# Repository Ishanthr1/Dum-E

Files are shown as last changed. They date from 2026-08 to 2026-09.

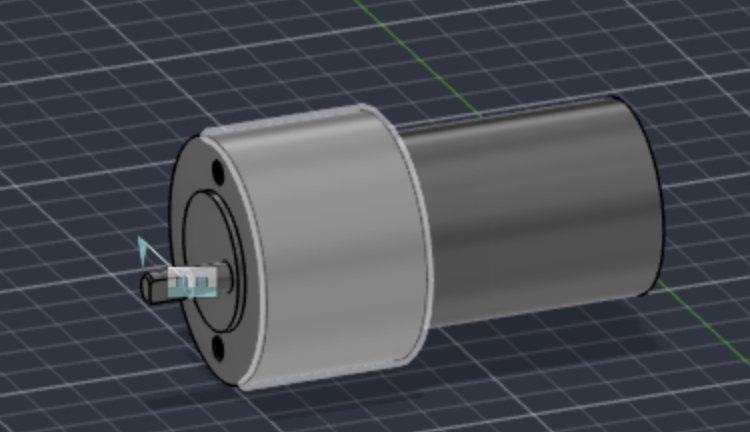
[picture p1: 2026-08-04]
images/Screenshot 2026-08-04 at 3.25.16 PM.png

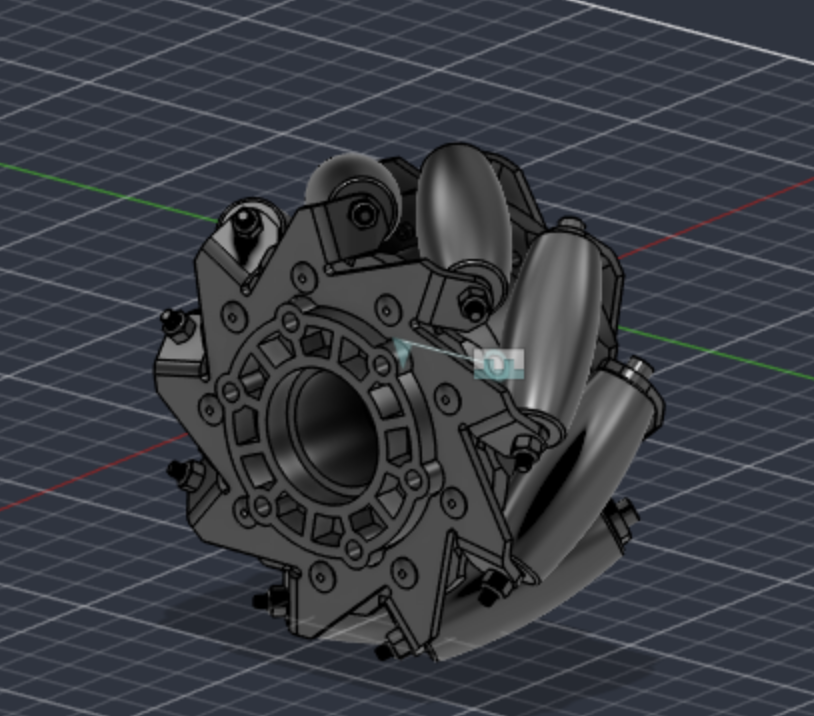
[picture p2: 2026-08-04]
images/Screenshot 2026-08-04 at 3.25.08 PM.png

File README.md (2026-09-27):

# Dum-E

A voice controlled autonomous mobile manipulator built from scratch. Dum-E is a 6 DOF robotic arm mounted on a holonomic (mecanum) drive base named after Tony Stark's clumsy robot assistant.

Screenshot 2026-08-04 at 3 30 15 PM

## Overview and How it Works

DumE is a robotic platform with two main sub assemblies: a holonomic drive base and a 6 DOF arm. Both the chassis and the arm are designed and built from scratch from individually sourced aluminum, hardware, and 3D printed parts.

- **Holonomic drive:** four mecanum wheels for omnidirectional movement (forward, strafe, and rotate in place).
- **6-DOF arm:** six high torque servos with a custom parallel jaw gripper.
- **Stereo vision head:** dual Raspberry Pi cameras at a fixed baseline.
- **Far-field audio:** ReSpeaker mic array plus an amplified speaker.

CAD files for the chassis, arm, and 3D printed parts are in the [`cad/`](cad/) folder.

## Why?

I have always been interested in Robotics and building this project can help me improve me skills. There are already many prebuilt things I can buy to help speed up this project but I want to make something actually worthwhile which is why I am building everything from scratch from individually sourced parts. I also wanted to make something cool!

## Bill of Materials

Full parts list (also available as [`BOM.csv`](BOM.csv)). A Raspberry Pi 5 is required but is owned separately and not included in the total below.

| Item | Qty | Unit (USD) | Total | Where to buy |
|---|-----|---|---|---|
| Hiwonder xArm1S 6DOF arm (unassembled) | 1 | 199.99 | 199.99 | [Amazon](https://www.amazon.com/Programming-Powerful-Intelligent-Featuring-Unassembled/dp/B08FT31C5N) |
| MC200 mecanum chassis + 4 encoder motors | 1 | 73.99 | 73.99 | [Amazon](https://www.amazon.com/dp/B09KL37P43) |
| Raspberry Pi Camera Module 3 | 2 | 36.00 | 72.00 | [Amazon](https://www.amazon.com/Arducam-Raspberry-Camera-Autofocus-15-22pin/dp/B0C9PYCV9S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) |
| microSD card | 1 | 33.06 | 33.06 | [Amazon](https://www.amazon.com/SanDisk-Extreme-microSDXC-Memory-Adapter/dp/B09X7C7LL1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) |
| LiPo battery 3S 11.1V (XT60) | 1 | 32.99 | 32.99 | [Amazon](https://www.amazon.com/OVONIC-Connector-Airplane-Helicopter-Quadcopter/dp/B0D8SFBHV6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) |
| Helping Hands | 1 | 25.99 | 25.99 | [Amazon](https://www.amazon.com/Helping-Soldering-Workshop-Non-slip-Weighted/dp/B07MDKXNPC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) |
| L298N dual H-bridge motor driver | 2 | 9.99 | 19.98 | [Amazon](https://www.amazon.com/BOJACK-H-Bridge-Controller-Intelligent-Mega2560/dp/B0C5JCF5RS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) |
| ESP32 dev board — motor controller | 1 | 18.99 | 18.99 | [Amazon](https://www.amazon.com/YEJMKJ-Development-ESP-WROOM-32-Microcontroller-Integrated/dp/B0CNGPQX2V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) |
| Buck converter 7.5V 6A — arm rail | 1 | 17.49 | 17.49 | [Amazon](https://www.amazon.com/s?k=DC-DC+buck+converter+7.5V+6A+adjustable) |
| LiPo balance charger (3S) | 1 | 16.99 | 16.99 | [Amazon](https://www.amazon.com/SSUPCHG-Battery-Charger-Balance-Chargers/dp/B0FPDJ5Q57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) |
| ReSpeaker 2-Mics Pi HAT | 1 | 13.99 | 13.99 | [Seeed Studio](https://www.seeedstudio.com/ReSpeaker-2-Mics-Pi-HAT.html) |
| Buck converter 5V 5A (UBEC) | 1 | 11.99 | 11.99 | [Amazon](https://www.amazon.com/EC-Buying-Mini560-Adjustable-Electronics/dp/B0GW8JMN9J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) |
| LiPo charging safety bag | 1 | 11.99 | 11.99 | [Amazon](https://www.amazon.com/HOOVO-Battery-Fireproof-Explosionproof-Protector/dp/B0B4SGTRDC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) |
| Pi 5 camera adapter cable | 1 | 9.99 | 9.99 | [Amazon](https://www.amazon.com/Wonrabai-2PCS-Official-Flexible-Compatible-Raspberry/dp/B0GJ5CJWDF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) |
| XT60 connectors + power wiring | 1 | 8.99 | 8.99 | [Amazon](https://www.amazon.com/Pairs-Female-Connector-Silicon-Battery/dp/B07QH249CR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) |
| Inline fuse holder + master switch | 1 | 8.99 | 8.99 | [Amazon](https://www.amazon.com/Gebildet-12V-220V-Button-Switch-Driving/dp/B0FJXTXZ43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) |
| Dupont jumper wire kit (M-M, M-F, F-F) | 1 | 8.99 | 8.99 | [Amazon](https://www.amazon.com/Solderless-Multicolor-Electronic-Breadboard-Protoboard/dp/B09FNXKXDW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) |
| Zip ties | 1 | 8.97 | 8.97 | [Amazon](https://www.amazon.com/Zip-Tie-Mounts-SeuYeugX-Management/dp/B08XLR46Y7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) |
| MAX98357A I2S amplifier | 1 | 6.88 | 6.88 | [Amazon](https://www.amazon.com/MAX98357-MAX98357A-Amplifier-Interface-Raspberry/dp/B0DPJRLMDJ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) |
| Micro-USB data cable (ESP32) | 1 | 6.59 | 6.59 | [Amazon](https://www.amazon.com/DIYmall-Micro-USB-Charging-Transfer-Android-Phone/dp/B0C89Q81FW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) |
| Speaker 3in 8Ω 1W | 1 | 5.58 | 5.58 | [Amazon](https://www.amazon.com/Micro-Internal-speaker-Small-Speakers/dp/B0H3PPB2HN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) |
| Velcro strips | 1 | 4.89 | 4.89 | [Amazon](https://www.amazon.com/Art3d-Sticky-Double-Sided-Command-Adhesive/dp/B0B58FGF8H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) |
| **Total** | | | **619.31** | |

## Build Journal

Day by day progress is logged in Journal.md.

## License

MIT see [`LICENSE`](LICENSE).

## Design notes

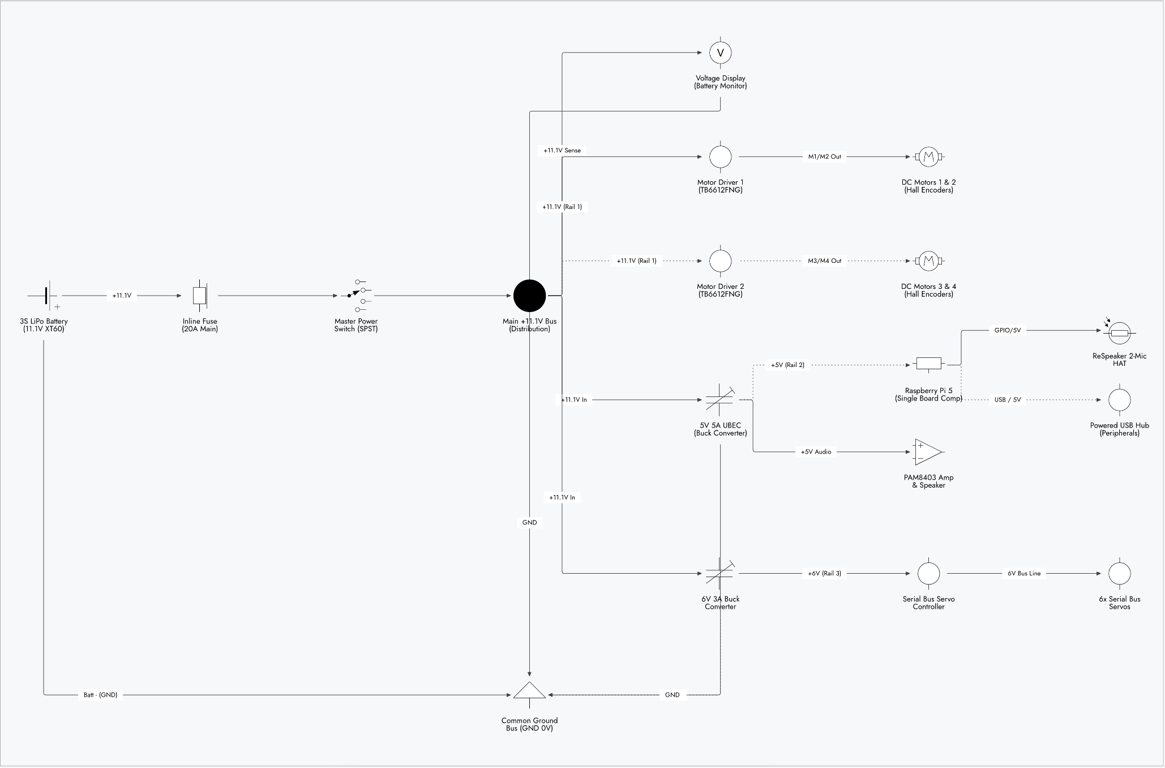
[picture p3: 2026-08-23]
DumE Schematics.png

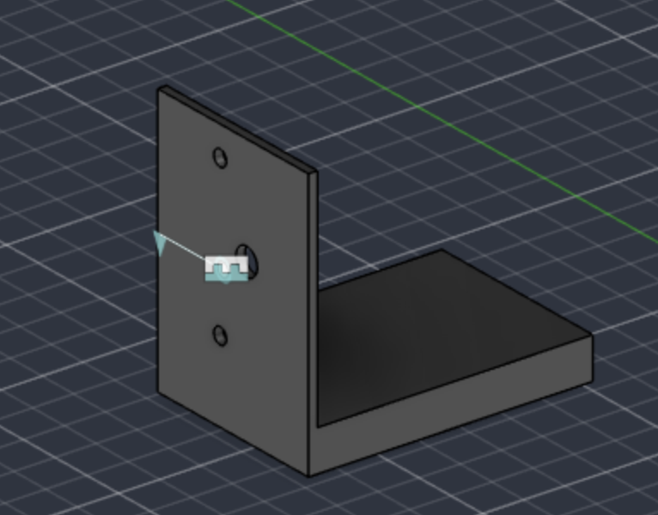
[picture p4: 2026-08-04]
images/Screenshot 2026-08-04 at 3.24.59 PM.png

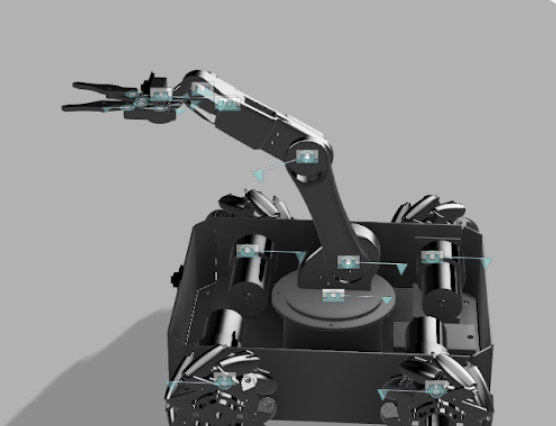
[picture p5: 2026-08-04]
images/Screenshot 2026-08-04 at 3.24.10 PM.png

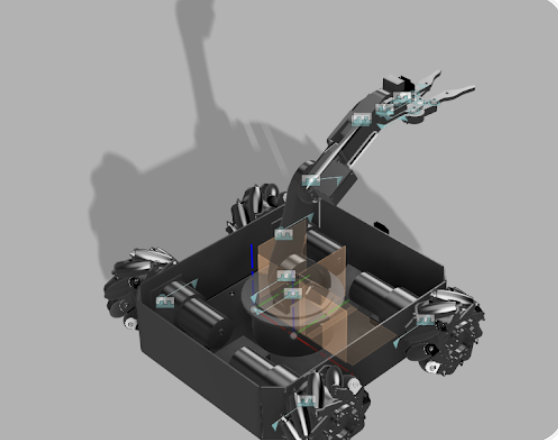
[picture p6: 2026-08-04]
images/Screenshot 2026-08-04 at 3.24.02 PM.png

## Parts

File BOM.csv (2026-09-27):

Item | Qty | Unit (USD) | Total (USD) | Where to buy | URL
Hiwonder xArm1S 6DOF arm (unassembled) | 1 | 199.99 | 199.99 | Amazon | https://www.amazon.com/Programming-Powerful-Intelligent-Featuring-Unassembled/dp/B08FT31C5N
MC200 mecanum chassis + 4 encoder motors | 1 | 73.99 | 73.99 | Amazon | https://www.amazon.com/dp/B09KL37P43
Raspberry Pi Camera Module 3 | 2 | 36.00 | 72.00 | Amazon | https://www.amazon.com/Arducam-Raspberry-Camera-Autofocus-15-22pin/dp/B0C9PYCV9S
Buck converter 7.5V 6A - arm rail | 1 | 17.49 | 17.49 | Amazon | https://www.amazon.com/s?k=DC-DC+buck+converter+7.5V+6A+adjustable
ReSpeaker 2-Mics Pi HAT | 1 | 13.99 | 13.99 | Seed Studio | https://www.seeedstudio.com/ReSpeaker-2-Mics-Pi-HAT.html
LiPo balance charger (3S) | 1 | 16.99 | 16.99 | Amazon | https://www.amazon.com/SSUPCHG-Battery-Charger-Balance-Chargers/dp/B0FPDJ5Q57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
Buck converter 5V 5A (UBEC) | 1 | 11.99 | 11.99 | Amazon | https://www.amazon.com/EC-Buying-Mini560-Adjustable-Electronics/dp/B0GW8JMN9J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
XT60 connectors + power wiring | 1 | 8.99 | 8.99 | Amazon | https://www.amazon.com/Pairs-Female-Connector-Silicon-Battery/dp/B07QH249CR?sp_csd=d2lkZ2V0TmFtZT1zcF9hdGY
Inline fuse holder + master switch | 1 | 8.99 | 8.99 | Amazon | https://www.amazon.com/Gebildet-12V-220V-Button-Switch-Driving/dp/B0FJXTXZ43
LiPo battery 3S 11.1V (XT60) | 1 | 32.99 | 32.99 | Amazon | https://www.amazon.com/OVONIC-Connector-Airplane-Helicopter-Quadcopter/dp/B0D8SFBHV6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
ESP32 dev board - motor controller | 1 | 18.99 | 18.99 | Amazon | https://www.amazon.com/YEJMKJ-Development-ESP-WROOM-32-Microcontroller-Integrated/dp/B0CNGPQX2V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
L298N dual H-bridge motor driver | 2 | 9.99 | 19.98 | Amazon | https://www.amazon.com/BOJACK-H-Bridge-Controller-Intelligent-Mega2560/dp/B0C5JCF5RS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
microSD card | 1 | 33.06 | 33.06 | Amazon | https://www.amazon.com/SanDisk-Extreme-microSDXC-Memory-Adapter/dp/B09X7C7LL1
Pi 5 camera adapter cable | 1 | 9.99 | 9.99 | Amazon | https://www.amazon.com/Wonrabai-2PCS-Official-Flexible-Compatible-Raspberry/dp/B0GJ5CJWDF?nsdOptOutParam=true
MAX98357A I2S amplifier | 1 | 6.88 | 6.88 | Amazon | https://www.amazon.com/MAX98357-MAX98357A-Amplifier-Interface-Raspberry/dp/B0DPJRLMDJ
Speaker 3in 8Ω 1W | 1 | 5.58 | 5.58 | Amazon | https://www.amazon.com/Micro-Internal-speaker-Small-Speakers/dp/B0H3PPB2HN
Micro-USB data cable (ESP32) | 1 | 6.59 | 6.59 | Amazon | https://www.amazon.com/DIYmall-Micro-USB-Charging-Transfer-Android-Phone/dp/B0C89Q81FW
LiPo charging safety bag | 1 | 11.99 | 11.99 | Amazon | https://www.amazon.com/HOOVO-Battery-Fireproof-Explosionproof-Protector/dp/B0B4SGTRDC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
Dupont jumper wire kit (M-M, M-F, F-F) | 1 | 8.99 | 8.99 | Amazon | https://www.amazon.com/Solderless-Multicolor-Electronic-Breadboard-Protoboard/dp/B09FNXKXDW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
Zip Ties | 1 | 8.97 | 8.97 | Amazon | https://www.amazon.com/Zip-Tie-Mounts-SeuYeugX-Management/dp/B08XLR46Y7?sp_csd=d2lkZ2V0TmFtZT1zcF9hdGY
Velcro Strips | 1 | 4.89 | 4.89 | Amazon | https://www.amazon.com/Art3d-Sticky-Double-Sided-Command-Adhesive/dp/B0B58FGF8H
Helping Hands | 1 | 25.99 | 25.99 | Amazon | https://www.amazon.com/Helping-Soldering-Workshop-Non-slip-Weighted/dp/B07MDKXNPC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

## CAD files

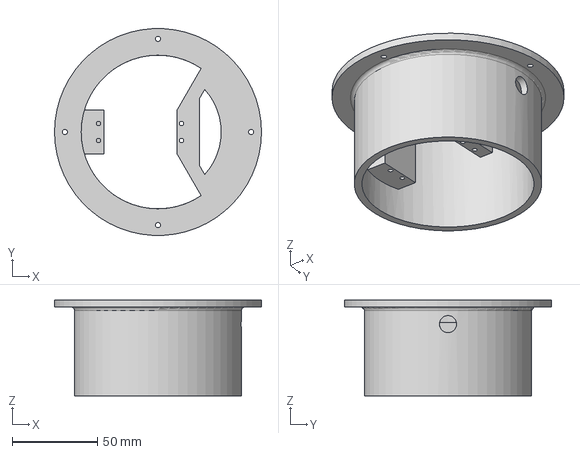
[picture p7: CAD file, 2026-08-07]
cad/base.stp
121.2 x 121.1 x 56.0 mm

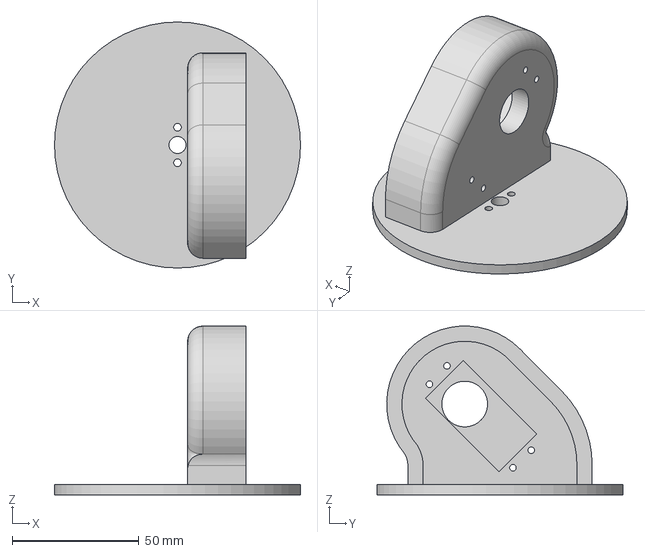
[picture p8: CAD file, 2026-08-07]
cad/Chassis+for+Robot.stp
97.0 x 97.0 x 66.5 mm

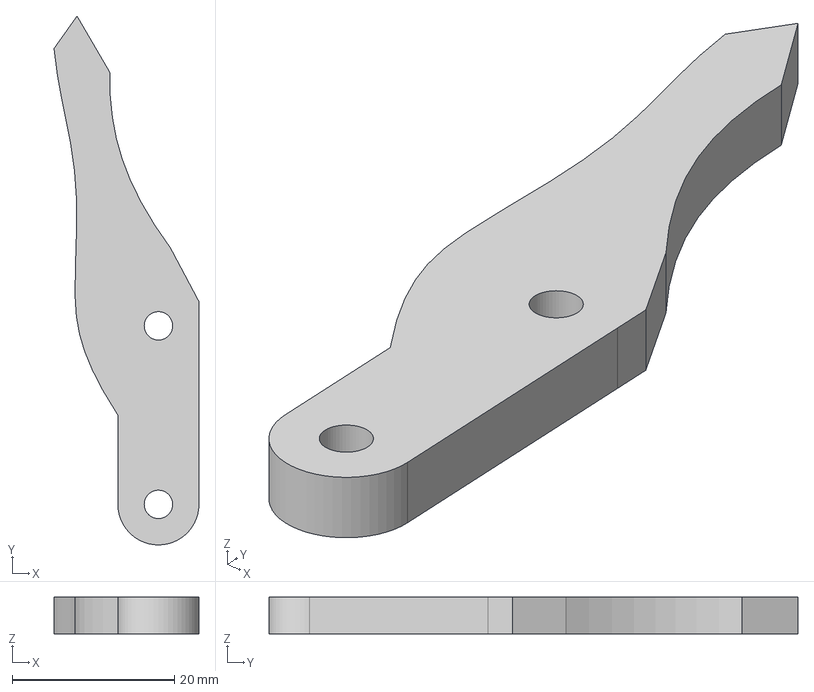
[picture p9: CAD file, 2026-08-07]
cad/Claw.stp
17.9 x 65.2 x 4.50 mm

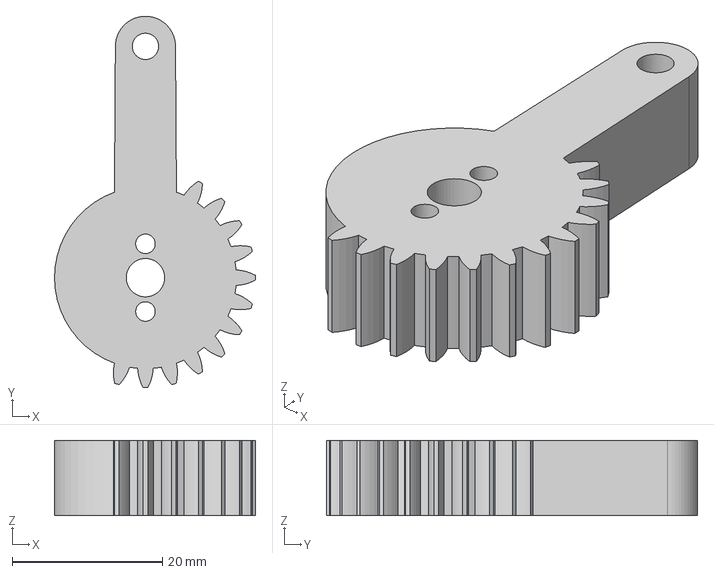
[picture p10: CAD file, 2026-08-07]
cad/Gear+for+Claw.stp
26.7 x 49.4 x 10.0 mm

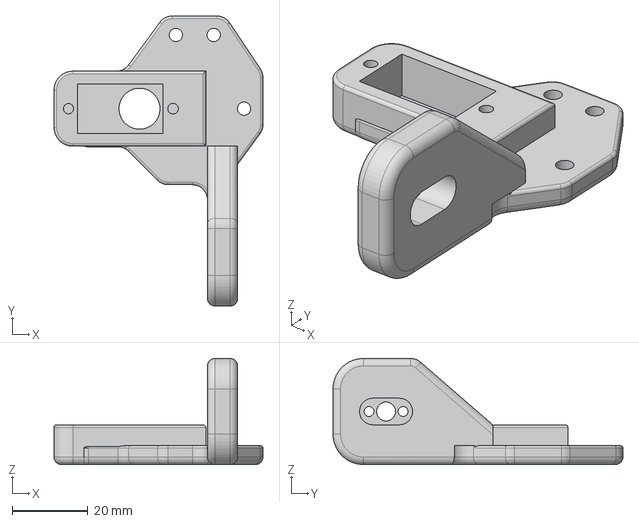
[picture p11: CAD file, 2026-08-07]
cad/Claw+Link.stp
55.2 x 76.5 x 28.0 mm

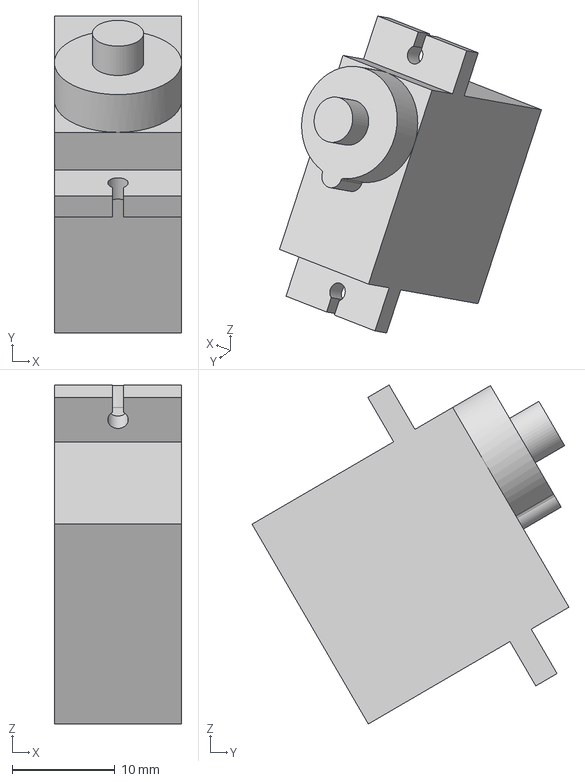
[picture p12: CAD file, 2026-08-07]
cad/Servo+2.stp
12.4 x 30.9 x 33.0 mm

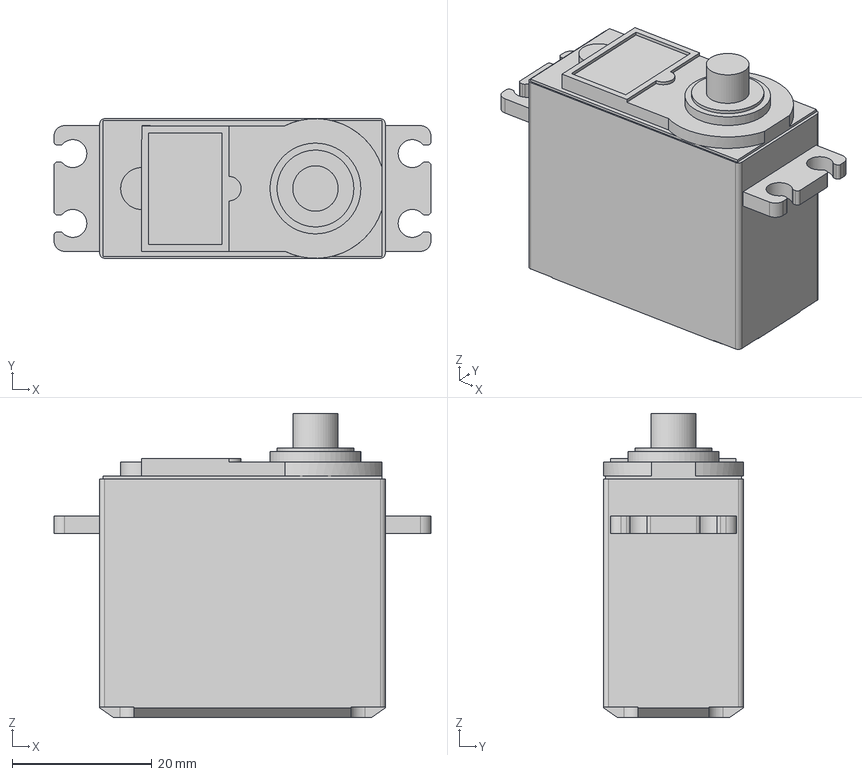
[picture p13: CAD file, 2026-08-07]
cad/Sservo+1.stp
54.0 x 20.0 x 43.6 mm

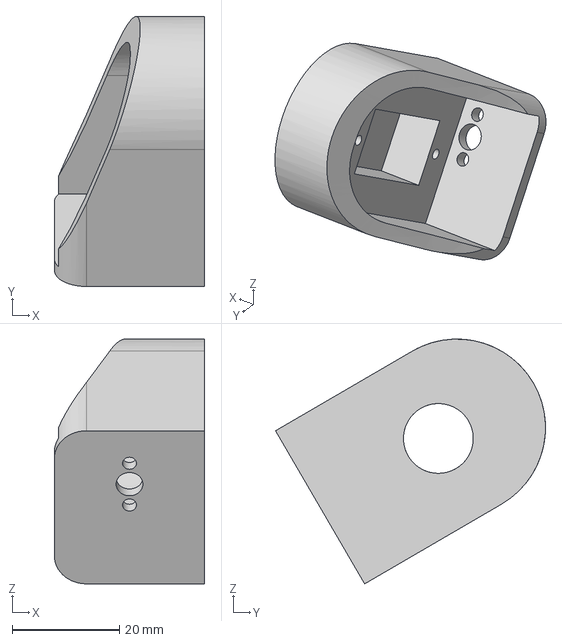
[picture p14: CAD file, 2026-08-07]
cad/Robot+Arm+3.stp
28.0 x 50.3 x 45.6 mm

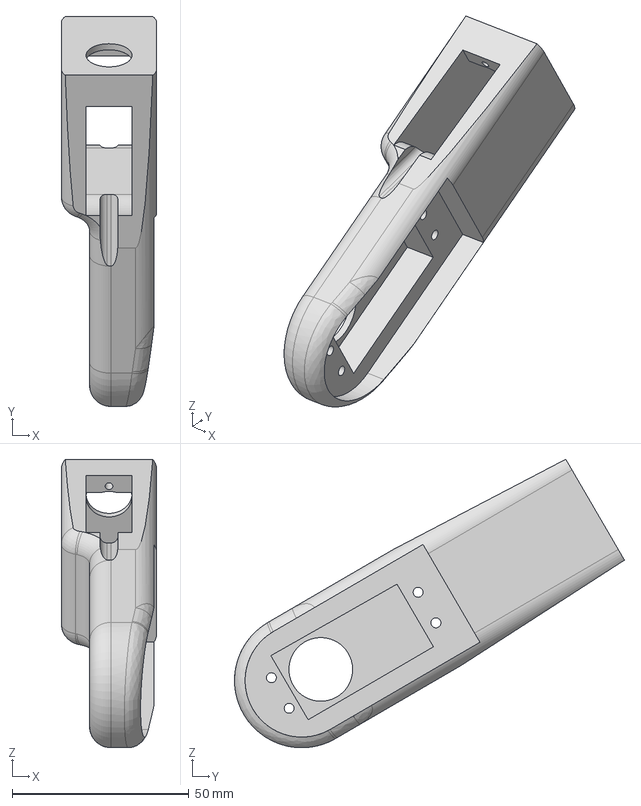
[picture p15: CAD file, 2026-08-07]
cad/Robot+Arm+2.stp
27.0 x 110.3 x 81.6 mm

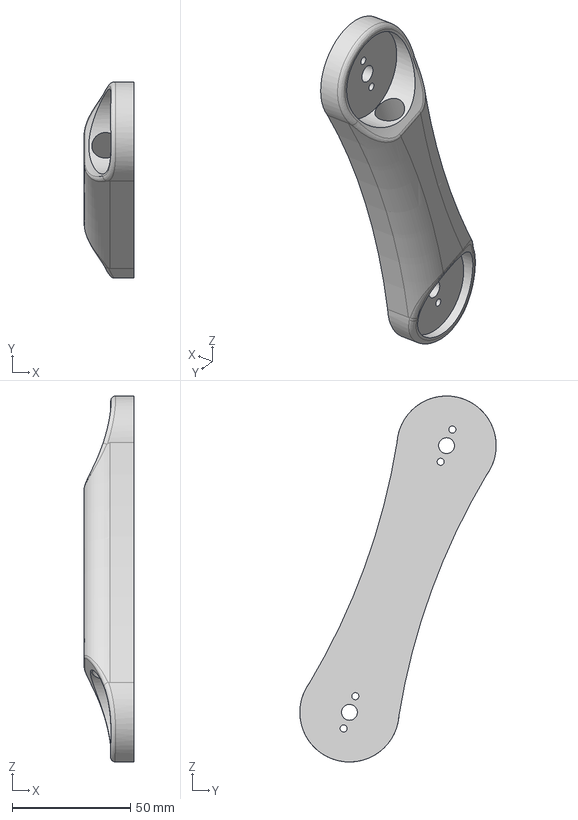
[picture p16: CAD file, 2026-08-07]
cad/Robot+Arm+1.stp
21.0 x 83.0 x 154.8 mm

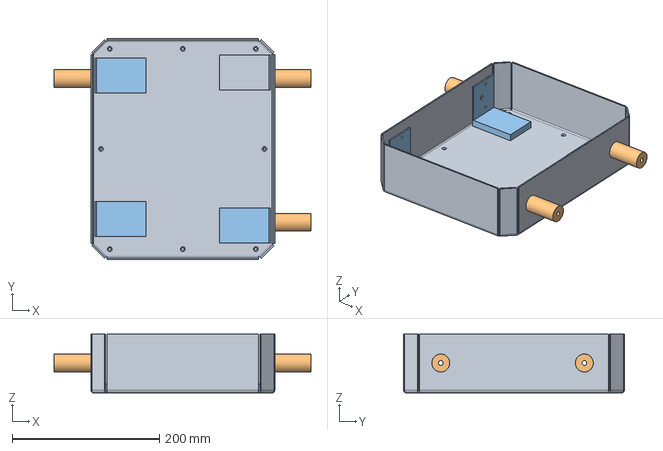
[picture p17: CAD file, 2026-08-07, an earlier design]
cad/Base (1).stp
349.1 x 300.0 x 80.0 mm

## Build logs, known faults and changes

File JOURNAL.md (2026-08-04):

# Dum-E Build Journal

DumE is a voice controlled autonomous mobile manipulator: a 6 DOF arm on a
holonomic (mecanum) drive base, with stereo vision, natural language control, and a
personality system. The chassis and arm are designed and built from
individually sourced components.

---

## June 19: Design Phase: Drive Base Layout
**Hours: 2**

- Started the CAD design for DumE and laid out the holonomic drive base footprint.
- Positioned the four mecanum wheels at the corners and set the roller angle to 45° for true omnidirectional travel; checked wheel clearance against the chassis edges.
- Blocked out the lower deck and planned where the four DC gear motors and the motor driver would sit.
- Locked in the overall proportions so the base is wide and low enough to stay stable once the arm is mounted on top.

Screenshot 2026-08-04 at 3 35 26 PM

---

## June 20: Design Phase: Arm Mount, Camera Housing & Electronics Bay
**Hours: 3**

- Added the rotating shoulder turret / arm mount at the rear center of the deck.
- Modeled the central electronics bay enclosure to house the Raspberry Pi 5 and the driver boards, plus a removable tray for the LiPo battery.
- Roughed in the camera housing for the stereo vision head.

- Worked out counterweight placement: the arm shifts the center of mass forward when extended, so I positioned the battery toward the rear to keep the platform from tipping.

Screenshot 2026-08-04 at 3 35 58 PM
Screenshot 2026-08-04 at 3 36 22 PM
Screenshot 2026-08-04 at 3 36 35 PM
Screenshot 2026-08-04 at 3 36 50 PM

---

## June 21: Design Phase: 6-DOF Arm & Gripper
**Hours: 4**

- Designed the full 6 DOF arm from scratch: shoulder, elbow, and wrist joints, each driven by a high torque servo in its own aluminum bracket.
- Sized the link segments (slim aluminum plates with lightening cutouts and cable channels) to keep the arm short and stout rather than gangly, so the servos aren't fighting a long moment arm.
- Designed the parallel jaw gripper as a single 3D printed assembly actuated by a small servo, with textured fingertips for grip.
- Sanity checked reach and joint ranges so the gripper can actually reach the ground and objects on the deck this feeds directly into the inverse kinematics work later.

Screenshot 2026-08-04 at 3 35 58 PM
Screenshot 2026-08-04 at 3 37 43 PM
Screenshot 2026-08-04 at 3 38 06 PM
Screenshot 2026-08-04 at 3 38 18 PM
Screenshot 2026-08-04 at 3 38 28 PM
Screenshot 2026-08-04 at 3 38 37 PM
Screenshot 2026-08-04 at 3 38 47 PM

---

## June 22: Design Phase: Vision Head, Power Routing & Scratch-Build Rework
**Hours: 4**

- Switched from off the shelf kit parts to a fully scratch built chassis and arm, and redid the CAD for cleaner, more precise geometry real brackets, fillets, and fastener holes instead of blocky placeholders.
- Designed the 3D printed pan tilt sensor head carrying the stereo camera pair (fixed baseline) with the ReSpeaker mic array disc mounted on top.
- Planned the power and wiring path: LiPo → buck converter → Pi 5 and logic, with a separate motor power rail and routing channels so no wires are left floating.
- Fixed assembly issues from the earlier draft so every part is connected and seated, with nothing detached.

Screenshot 2026-08-04 at 3 39 04 PM
Screenshot 2026-08-04 at 3 39 29 PM

---

## June 23: Design Phase: Final Review & Submission
**Hours: 2**

- Finished the full design and reviewed it from all angles (iso, top, front, side) to confirm fit and clearances.
- Exported the CAD files and added them to the repository.

Screenshot 2026-08-04 at 3 39 58 PM
Screenshot 2026-08-04 at 3 40 07 PM
Screenshot 2026-08-04 at 3 40 17 PM
Screenshot 2026-08-04 at 3 40 25 PM
Screenshot 2026-08-04 at 3 40 35 PM

---

**Total hours: 15**

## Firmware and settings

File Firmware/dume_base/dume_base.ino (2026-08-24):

#include <Arduino.h>
#include "config.h"
#include "encoders.h"
#include "motors.h"
#include "kinematics.h"
#include "pid.h"

static VelocityPid s_pid[WHEEL_COUNT];
static float s_targetWheelVel[WHEEL_COUNT];
static float s_measWheelVel[WHEEL_COUNT];

static float s_cmdVx = 0.0f, s_cmdVy = 0.0f, s_cmdWz = 0.0f;

static float s_poseX = 0.0f, s_poseY = 0.0f, s_poseTheta = 0.0f;
static float s_bodyVx = 0.0f, s_bodyVy = 0.0f, s_bodyWz = 0.0f;

static uint32_t s_lastControlMs = 0;
static uint32_t s_lastTelemetryMs = 0;
static uint32_t s_lastCommandMs = 0;

static bool s_openLoop = false;
static int16_t s_openLoopDuty[WHEEL_COUNT];

static char s_rxBuf[SERIAL_RX_BUFFER];
static uint8_t s_rxLen = 0;

static void applyStop() {
  s_cmdVx = s_cmdVy = s_cmdWz = 0.0f;
  for (uint8_t i = 0; i < WHEEL_COUNT; ++i) {
    s_targetWheelVel[i] = 0.0f;
    s_openLoopDuty[i] = 0;
    s_pid[i].reset();
  }
  motors::stopAll();
}

static void handleLine(char* line) {
  char* tok = strtok(line, " \t");
  if (tok == NULL) return;

  switch (tok[0]) {
    case 'V': {
      char* sx = strtok(NULL, " \t");
      char* sy = strtok(NULL, " \t");
      char* sw = strtok(NULL, " \t");
      if (!sx || !sy || !sw) {
        Serial.println(F("ERR V needs 3 args"));
        return;
      }
      s_cmdVx = atof(sx);
      s_cmdVy = atof(sy);
      s_cmdWz = atof(sw);
      kinematics::clampCommand(&s_cmdVx, &s_cmdVy, &s_cmdWz);
      kinematics::inverse(s_cmdVx, s_cmdVy, s_cmdWz, s_targetWheelVel);
      s_openLoop = false;
      s_lastCommandMs = millis();
      break;
    }

    case 'S':
      applyStop();
      s_lastCommandMs = millis();
      break;

    case 'R':
      s_poseX = s_poseY = s_poseTheta = 0.0f;
      encoders::resetTotals();
      s_lastCommandMs = millis();
      break;

    case 'M': {
      char* sw = strtok(NULL, " \t");
      char* sd = strtok(NULL, " \t");
      if (!sw || !sd) {
        Serial.println(F("ERR M needs 2 args"));
        return;
      }
      const int wheel = atoi(sw);
      if (wheel < 0 || wheel >= WHEEL_COUNT) {
        Serial.println(F("ERR wheel out of range"));
        return;
      }
      s_openLoop = true;
      s_openLoopDuty[wheel] = (int16_t)atoi(sd);
      s_lastCommandMs = millis();
      break;
    }

    case 'C':
      s_openLoop = false;
      for (uint8_t i = 0; i < WHEEL_COUNT; ++i) {
        s_openLoopDuty[i] = 0;
        s_pid[i].reset();
      }
      s_lastCommandMs = millis();
      break;

    case 'I': {
      char* sw = strtok(NULL, " \t");
      char* sv = strtok(NULL, " \t");
      if (!sw || !sv) {
        Serial.println(F("ERR I needs 2 args"));
        return;
      }
      const int wheel = atoi(sw);
      if (wheel < 0 || wheel >= WHEEL_COUNT) {
        Serial.println(F("ERR wheel out of range"));
        return;
      }
      motors::setInverted((uint8_t)wheel, atoi(sv) != 0);
      s_lastCommandMs = millis();
      break;
    }

    case 'P':
      Serial.println(F("PONG"));
      s_lastCommandMs = millis();
      break;

    default:
      Serial.println(F("ERR unknown command"));
      break;
  }
}

static void pollSerial() {
  while (Serial.available() > 0) {
    const char c = (char)Serial.read();

    if (c == '\n' || c == '\r') {
      if (s_rxLen > 0) {
        s_rxBuf[s_rxLen] = '\0';
        handleLine(s_rxBuf);
        s_rxLen = 0;
      }
      continue;
    }

    if (s_rxLen < SERIAL_RX_BUFFER - 1) {
      s_rxBuf[s_rxLen++] = c;
    } else {
      s_rxLen = 0;
      Serial.println(F("ERR line too long"));
    }
  }
}

static void runControl(float dt) {
  int32_t delta[WHEEL_COUNT];
  encoders::readAndResetDelta(delta);

  const float radPerCount = TWO_PI / COUNTS_PER_REV;
  for (uint8_t i = 0; i < WHEEL_COUNT; ++i) {
    s_measWheelVel[i] = ((float)delta[i] * radPerCount) / dt;
  }

  kinematics::forward(s_measWheelVel, &s_bodyVx, &s_bodyVy, &s_bodyWz);
  const float midTheta = s_poseTheta + s_bodyWz * dt * 0.5f;
  s_poseX += (s_bodyVx * cos(midTheta) - s_bodyVy * sin(midTheta)) * dt;
  s_poseY += (s_bodyVx * sin(midTheta) + s_bodyVy * cos(midTheta)) * dt;
  s_poseTheta += s_bodyWz * dt;

  while (s_poseTheta >  PI) s_poseTheta -= TWO_PI;
  while (s_poseTheta <= -PI) s_poseTheta += TWO_PI;

  if (s_openLoop) {
    for (uint8_t i = 0; i < WHEEL_COUNT; ++i) {
      motors::setWheel(i, s_openLoopDuty[i]);
    }
    return;
  }

  for (uint8_t i = 0; i < WHEEL_COUNT; ++i) {
    const int16_t duty = s_pid[i].update(s_targetWheelVel[i], s_measWheelVel[i], dt);
    motors::setWheel(i, duty);
  }
}

static void sendTelemetry() {
  int32_t totals[WHEEL_COUNT];
  encoders::readTotals(totals);

  Serial.print(F("O "));
  Serial.print(s_poseX, 4);     Serial.print(' ');
  Serial.print(s_poseY, 4);     Serial.print(' ');
  Serial.print(s_poseTheta, 4); Serial.print(' ');
  Serial.print(s_bodyVx, 3);    Serial.print(' ');
  Serial.print(s_bodyVy, 3);    Serial.print(' ');
  Serial.print(s_bodyWz, 3);
  for (uint8_t i = 0; i < WHEEL_COUNT; ++i) {
    Serial.print(' ');
    Serial.print(totals[i]);
  }
  Serial.println();
}

void setup() {
  Serial.begin(SERIAL_BAUD);

  motors::begin();
  encoders::begin();
  applyStop();

  const uint32_t now = millis();
  s_lastControlMs = now;
  s_lastTelemetryMs = now;
  s_lastCommandMs = now - COMMAND_TIMEOUT_MS;

  Serial.println(F("BOOT"));
}

void loop() {
  pollSerial();

  const uint32_t now = millis();

  if (now - s_lastCommandMs > COMMAND_TIMEOUT_MS) {
    if (s_cmdVx != 0.0f || s_cmdVy != 0.0f || s_cmdWz != 0.0f || s_openLoop) {
      applyStop();
      s_openLoop = false;
    }
  }

  if (now - s_lastControlMs >= CONTROL_PERIOD_MS) {
    const float dt = (float)(now - s_lastControlMs) * 0.001f;
    s_lastControlMs = now;
    runControl(dt);
  }

  if (now - s_lastTelemetryMs >= TELEMETRY_PERIOD_MS) {
    s_lastTelemetryMs = now;
    sendTelemetry();
  }
}

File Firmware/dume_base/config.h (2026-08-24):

#pragma once

#include <Arduino.h>

enum WheelIndex : uint8_t {
  WHEEL_FL = 0,
  WHEEL_FR = 1,
  WHEEL_RL = 2,
  WHEEL_RR = 3,
  WHEEL_COUNT = 4
};

const uint8_t MOTOR_PWM_PIN[WHEEL_COUNT] = { 9, 10, 11, 3 };
const uint8_t MOTOR_IN1_PIN[WHEEL_COUNT] = { 7, 12, A0, A2 };
const uint8_t MOTOR_IN2_PIN[WHEEL_COUNT] = { 8, 13, A1, A3 };

const uint8_t MOTOR_MIN_PWM = 40;
const uint8_t MOTOR_MAX_PWM = 255;

const uint8_t ENCODER_A_PIN[WHEEL_COUNT] = { 2, 4, 5, 6 };

const float COUNTS_PER_REV = 330.0f;

const float WHEEL_RADIUS = 0.040f;
const float WHEEL_BASE_X = 0.100f;
const float WHEEL_BASE_Y = 0.110f;

const float MAX_LINEAR_VEL  = 0.60f;
const float MAX_ANGULAR_VEL = 3.00f;

const uint16_t CONTROL_PERIOD_MS   = 20;
const uint16_t TELEMETRY_PERIOD_MS = 50;

const uint16_t COMMAND_TIMEOUT_MS = 500;

const float PID_KP = 6.0f;
const float PID_KI = 12.0f;
const float PID_KD = 0.0f;

const float PID_I_LIMIT = 120.0f;

const float PID_FEEDFORWARD = 14.0f;

const uint32_t SERIAL_BAUD = 115200;
const uint8_t  SERIAL_RX_BUFFER = 64;

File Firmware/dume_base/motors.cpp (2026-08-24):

#include "motors.h"
#include "encoders.h"

static bool s_inverted[WHEEL_COUNT];

namespace motors {

void begin() {
  for (uint8_t i = 0; i < WHEEL_COUNT; ++i) {
    pinMode(MOTOR_PWM_PIN[i], OUTPUT);
    pinMode(MOTOR_IN1_PIN[i], OUTPUT);
    pinMode(MOTOR_IN2_PIN[i], OUTPUT);
    s_inverted[i] = false;
    coast(i);
  }
}

void setInverted(uint8_t wheel, bool inverted) {
  if (wheel >= WHEEL_COUNT) return;
  s_inverted[wheel] = inverted;
}

void coast(uint8_t wheel) {
  if (wheel >= WHEEL_COUNT) return;
  analogWrite(MOTOR_PWM_PIN[wheel], 0);
  digitalWrite(MOTOR_IN1_PIN[wheel], LOW);
  digitalWrite(MOTOR_IN2_PIN[wheel], LOW);
}

void setWheel(uint8_t wheel, int16_t duty) {
  if (wheel >= WHEEL_COUNT) return;

  if (s_inverted[wheel]) duty = -duty;

  const int8_t dir = (duty >= 0) ? 1 : -1;
  encoders::setAssumedDirection(wheel, dir);

  uint16_t magnitude = (duty >= 0) ? (uint16_t)duty : (uint16_t)(-duty);
  if (magnitude > MOTOR_MAX_PWM) magnitude = MOTOR_MAX_PWM;

  if (magnitude < MOTOR_MIN_PWM) {
    coast(wheel);
    return;
  }

  if (dir > 0) {
    digitalWrite(MOTOR_IN1_PIN[wheel], HIGH);
    digitalWrite(MOTOR_IN2_PIN[wheel], LOW);
  } else {
    digitalWrite(MOTOR_IN1_PIN[wheel], LOW);
    digitalWrite(MOTOR_IN2_PIN[wheel], HIGH);
  }
  analogWrite(MOTOR_PWM_PIN[wheel], (uint8_t)magnitude);
}

void stopAll() {
  for (uint8_t i = 0; i < WHEEL_COUNT; ++i) coast(i);
}

}

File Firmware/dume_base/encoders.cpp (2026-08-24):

#include "encoders.h"

static const uint8_t kPortDMask[WHEEL_COUNT] = {
  _BV(PD2), _BV(PD4), _BV(PD5), _BV(PD6)
};

static volatile int32_t s_delta[WHEEL_COUNT];
static volatile int32_t s_total[WHEEL_COUNT];
static volatile int8_t  s_dir[WHEEL_COUNT];
static volatile uint8_t s_prevPortD;

namespace encoders {

void begin() {
  for (uint8_t i = 0; i < WHEEL_COUNT; ++i) {
    pinMode(ENCODER_A_PIN[i], INPUT_PULLUP);
    s_delta[i] = 0;
    s_total[i] = 0;
    s_dir[i] = 1;
  }

  s_prevPortD = PIND;

  PCICR |= _BV(PCIE2);
  PCMSK2 |= _BV(PCINT18) | _BV(PCINT20) | _BV(PCINT21) | _BV(PCINT22);
}

void setAssumedDirection(uint8_t wheel, int8_t dir) {
  if (wheel >= WHEEL_COUNT) return;
  s_dir[wheel] = dir;
}

void readCounts(int32_t* dest) {
  const uint8_t sreg = SREG;
  cli();
  for (uint8_t i = 0; i < WHEEL_COUNT; ++i) dest[i] = s_delta[i];
  SREG = sreg;
}

void readAndResetDelta(int32_t* dest) {
  const uint8_t sreg = SREG;
  cli();
  for (uint8_t i = 0; i < WHEEL_COUNT; ++i) {
    dest[i] = s_delta[i];
    s_delta[i] = 0;
  }
  SREG = sreg;
}

void readTotals(int32_t* dest) {
  const uint8_t sreg = SREG;
  cli();
  for (uint8_t i = 0; i < WHEEL_COUNT; ++i) dest[i] = s_total[i];
  SREG = sreg;
}

void resetTotals() {
  const uint8_t sreg = SREG;
  cli();
  for (uint8_t i = 0; i < WHEEL_COUNT; ++i) s_total[i] = 0;
  SREG = sreg;
}

}

ISR(PCINT2_vect) {
  const uint8_t now = PIND;
  const uint8_t changed = now ^ s_prevPortD;
  s_prevPortD = now;

  const uint8_t rising = changed & now;

  for (uint8_t i = 0; i < WHEEL_COUNT; ++i) {
    if (rising & kPortDMask[i]) {
      s_delta[i] += s_dir[i];
      s_total[i] += s_dir[i];
    }
  }
}

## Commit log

2026-08-04 Add new file cad/v
2026-08-15 Update servo price and total cost in README
2026-09-12 Fix link formatting for LiPo battery entry
2026-09-12 Revise Bill of Materials with total costs and new format
    Updated the Bill of Materials section with a new table format, added total costs for items, and adjusted pricing for some components.
2026-09-27 Update LiPo charging safety bag entry in BOM
    Replaced the old LiPo charging safety bag entry with a new one that has a different price.
    [BOM.csv]
